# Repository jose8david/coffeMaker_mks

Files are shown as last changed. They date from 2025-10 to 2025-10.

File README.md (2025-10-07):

# ☕ Proyecto de domotización de la cafetera Dolce Gusto del Makespace

Este proyecto tiene como objetivo **domotizar una cafetera de cápsulas Nescafé Dolce Gusto de Krups**.  
En concreto, se pretende:

- 🔸 Automatizar el **tiempo de dispensación del café**.  
- 🔸 Automatizar el **encendido y apagado** cuando la máquina permanezca inactiva.

---

## Cómo hacerse un café

Para preparar un café, sigue estos pasos:

1. **Enciende la máquina** mediante el botón lateral derecho con las marcas `0/I`.  
   La posición `I` indica que la máquina está encendida.
2. **Coloca la cápsula** en su soporte y ciérralo correctamente.  
3. **Espera** a que el **LED verde** situado encima del soporte deje de parpadear y se mantenga fijo.  
4. **Pulsa una vez el botón amarillo**, situado junto al botón de encendido/apagado general (`0/I`).

---

## Funcionamiento de la domotización

Después de realizar las cuatro operaciones anteriores, la máquina **suministra agua caliente** a través de la cápsula durante **20 segundos**. ¡Tenemos café!

- Si se vuelve a pulsar el **botón amarillo** durante este proceso, la máquina **detiene inmediatamente** la dispensación de agua (modo de parada de emergencia).  
- Al volver a pulsarlo, **reanuda la operación** durante otros 20 segundos.

Además:

- Si transcurren **dos minutos sin pulsar el botón amarillo**, la máquina **desconecta el calderín**, aunque **no se apaga por completo**. Por ello, **es importante dejar el botón lateral en la posición `0`** cuando no se vaya a utilizar.

---

## Explicación sencilla del circuito

Al conectar la máquina a la corriente y colocar el botón de encendido en la posición `I`, se genera un voltaje de 5 V.  
Este voltaje pasa por un diodo (para evitar inversiones de polaridad) y alimenta los siguientes componentes:

-  **ESP8266**
-  **Dos relés**, que controlan:
  - El **calderín** (pin D3)
  - La **bomba de agua** (pin D4)
- **Un botón**, conectado con una resistencia de **10 kΩ** en configuración *pull-up* al pin D2.
- **Un sensor NTC**, conectado como divisor de tensión con una resistencia de **100 kΩ** al pin A0.  
  El divisor se alimenta con **3,3 V** procedentes del propio ESP8266.

---

### Proceso de funcionamiento

1. Al encender la máquina, el **calderín comienza a calentarse** hasta alcanzar una temperatura aproximada de **60 °C a 70 °C**.  
   (Se supone que el circuito original incluye alguna protección, como un **fusible térmico**, para cortar la corriente al calderín en caso de sobrecalentamiento).

2. Mientras tanto, el ESP8266 permanece a la espera de que se pulse el botón amarillo (una vez la cápsula esté colocada y el LED verde se mantenga fijo).

3. Al pulsar el botón:
   - El ESP8266 lee la temperatura mediante el NTC, que está en contacto con el calderín.  
   - Si la temperatura igual o supera los 60 °C, se activa el relé que controla la bomba de agua.

4. El relé de la bomba se mantiene cerrado durante 20 segundos, tiempo durante el cual la máquina dispensa agua caliente a través de la cápsula.

---

## Componentes principales

| Componente | Función | Pin del ESP8266 |
|---|---|---|
| Relé 1 | Control del calderín | D3~0 |
| Relé 2 | Control de la bomba de agua | D4~2 |
| Botón amarillo | Activación de la dispensación | D2~4 |
| Sensor NTC | Lectura de temperatura del calderín | A0~A0 |

---

## 📜 ANÍMATE A SEGUIR CON EL PROYECTO

- 💡 Pon el funcionamiento las tiras LED que cubren la carcasa de la cafetera. ¿Qué tal si indicasen el tiempo de inactividad? ¿ o la temperatura?
- 💡 Conecta el ESP8266 a internet y avanza con la domotización

---

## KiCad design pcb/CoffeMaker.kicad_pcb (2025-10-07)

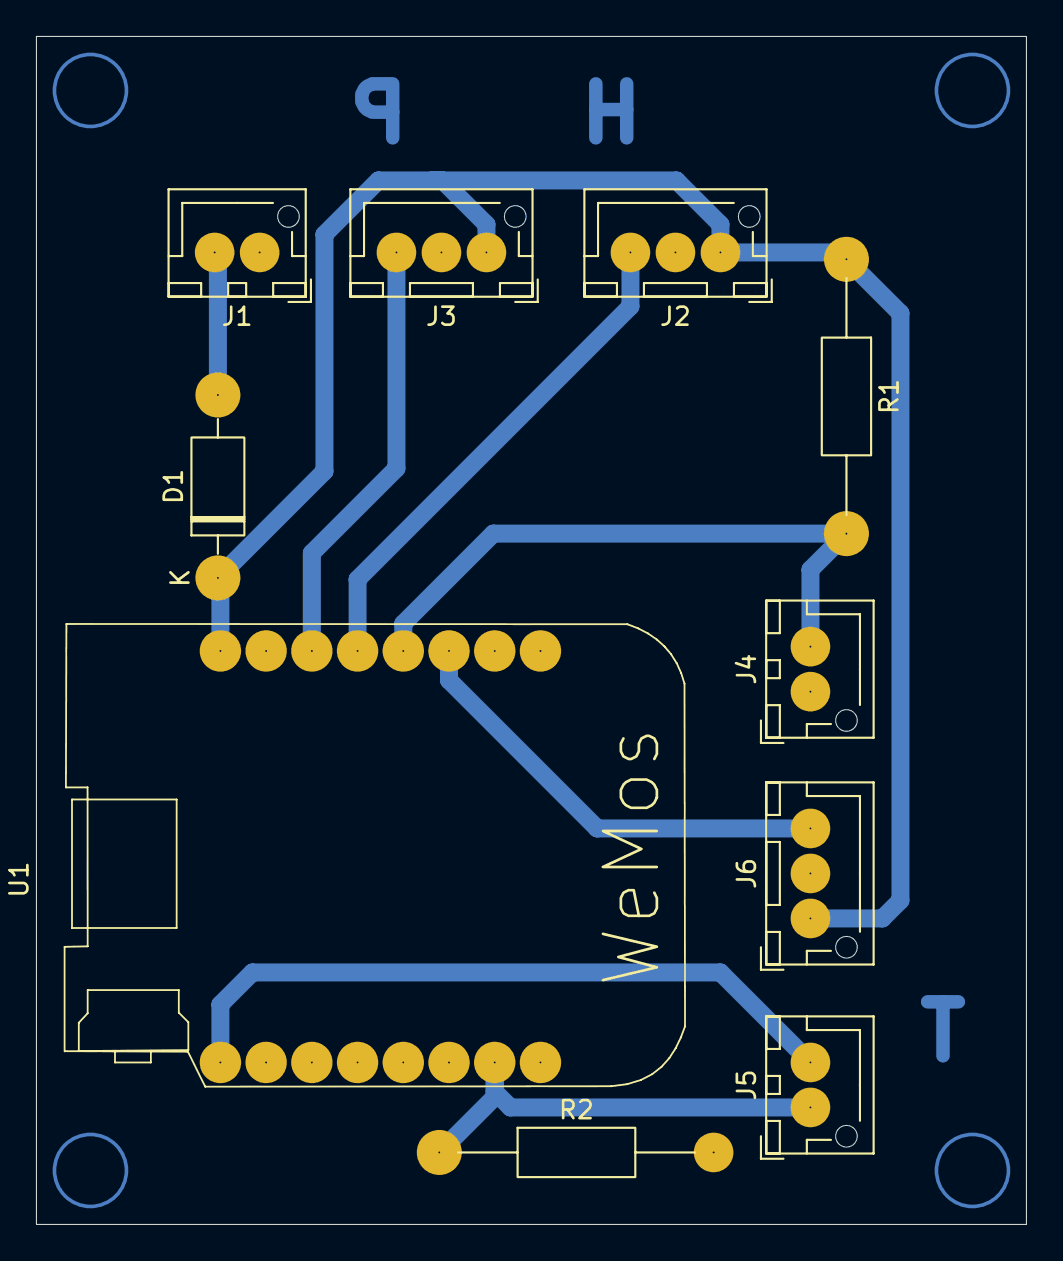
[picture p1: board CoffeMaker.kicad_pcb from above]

Board: 2 copper layers, 55.0 x 66.0 mm, 10 parts (0 on the bottom side), 9 nets.

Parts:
D1: SB130; D_DO-41_SOD81_P10.16mm_Horizontal
J1: POWER; JST_XH_B2B-XH-AM_1x02_P2.50mm_Vertical
J2: HEATER_RELAY; JST_XH_B3B-XH-AM_1x03_P2.50mm_Vertical
J3: PUMP_RELAY; JST_XH_B3B-XH-AM_1x03_P2.50mm_Vertical
J4: POWER_BUTTON; JST_XH_B2B-XH-AM_1x02_P2.50mm_Vertical
J5: TEMP_SENSOR; JST_XH_B2B-XH-AM_1x02_P2.50mm_Vertical
J6: LED_STRIP; JST_XH_B3B-XH-AM_1x03_P2.50mm_Vertical
R1: 10K; R_Axial_DIN0207_L6.3mm_D2.5mm_P15.24mm_Horizontal
R2: 100K; R_Axial_DIN0207_L6.3mm_D2.5mm_P15.24mm_Horizontal
U1: Wemos mini D1 ESP8266; D1_mini_board

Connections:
+3V3: J5.2, U1.16 (3.3V)
+5V: D1.1 (K), J2.1, J3.1, J6.1, R1.1, U1.e (5V)
BTN: J4.2, R1.2, U1.5 (D2)
GND: J1.1, J2.2, J3.2, J4.1, J6.2, R2.2, U1.2 (GND)
HEATER: J2.3, U1.4 (D3)
LED: J6.3, U1.6 (D1)
unnamed: D1.2 (A), J1.2
PUMP: J3.3, U1.3 (D4)
TMP: J5.1, R2.1, U1.10 (A0)

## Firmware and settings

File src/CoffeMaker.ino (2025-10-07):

#include "CoffeMaker.h"

const int buttonPin = 4; //D2-4
const int heaterRelayPin= 0 ; //D3-0
const int pumpRelayPin = 2; //D4-2
const int ntcPin = A0; //A0

CoffeeMaker mksCoffee (buttonPin, heaterRelayPin, pumpRelayPin, ntcPin);

void setup(){
  mksCoffee.start();
}

void loop(){
  mksCoffee.update();
}

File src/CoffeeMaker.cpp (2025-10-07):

#include "CoffeMaker.h"
#include "Arduino.h"

CoffeeMaker::CoffeeMaker(int buttonPin, int heaterRelayPin, int pumpRelayPin, int ntcPin)
    :button (buttonPin),
    heaterRelay (heaterRelayPin),
    pumpRelay(pumpRelayPin), 
    tempSensor(ntcPin){}

void CoffeeMaker::start(){
    Serial.begin(9600);
    Serial.println("Iniciando el sistema...");
    heaterOn();
    lastActionTime = millis();
}

void CoffeeMaker::heaterOn(){
    heaterRelay.activate();
    heating = true;
    Serial.println("Calderín encendido");
}

void CoffeeMaker::update(){
  button.update(); 
    if(button.isPressed()){
        if(makingCoffeeStatus){
            Serial.println("Botón pulsado. Parada de emergencia");
            stopMakingCoffee();
        } else {
            Serial.println("Botón pulsado: Comprobando la temperatura para hacer un café");
            if(heating){
                if(isHot()){
                    makingCoffee();
                } else {
                    Serial.println("El agua todavía no está caliente. Espera un poco");
                }
            } else {
                Serial.println("Encendiendo la máquina");
                heaterOn();
            }
        }
        lastActionTime = millis();
    }

    if(makingCoffeeStatus && (millis() - makingCoffeeTime) > 20000){
        Serial.println("Tiempo de preparación agotado. Parando la máquina");
        stopMakingCoffee();
    }

    offTime();

}

void CoffeeMaker::makingCoffee(){
    if(!isHot()){
        Serial.println("No puedo preparar el café, el agua no está caliente");
        return;
    }
    pumpRelay.activate();
    makingCoffeeStatus = true;
    makingCoffeeTime = millis();
    Serial.println("Iniciando la preparación del café (20 segundos)");

}

void CoffeeMaker::stopMakingCoffee(){
    pumpRelay.deactivate();
    makingCoffeeStatus = false;
    Serial.println("Se ha detenido la preparación del café");
}

bool CoffeeMaker::isHot(){
    float temp = tempSensor.readTemperature();
    if(temp >= 60.0){
        return true;
    }
        return false;

}

void CoffeeMaker::offTime(){
    if(!makingCoffeeStatus && heating){
        if((millis() - lastActionTime) > 120000){
            Serial.println("Inactividad de la cafetera");
            heaterOff();
        }
    }
}

void CoffeeMaker::heaterOff(){
    heating = false;
    heaterRelay.deactivate();
    stopMakingCoffee();
    Serial.println("Calentador apagado. Cafetera inactiva");
}

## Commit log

2025-10-07 Archivos del código y de la PCB
    [CoffeMaker.kicad_pcb, CoffeMaker.kicad_sch]
2025-10-07 Documentación mínima que explica el funcionamiento de la cafetera
